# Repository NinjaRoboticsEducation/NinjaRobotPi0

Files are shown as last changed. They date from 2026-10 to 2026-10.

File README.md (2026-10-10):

# NinjaRobotPi0

<div align="center">

**An Educational Raspberry Pi Zero 2 W Robot — Build It, Program It, Bring It to Life**






</div>

---

**🌐 Language / 言語 / 語言 / 语言:**
[English](#english) ・ [日本語](#日本語) ・ [繁體中文](#繁體中文) ・ [简体中文](#简体中文)

---

<!-- ENGLISH -->

# English

## 1. What Is NinjaRobotPi0?

**NinjaRobotPi0** is an open-source, modular educational robot built on the **Raspberry Pi Zero 2 W** (a tiny, affordable computer about the size of a stick of gum). It brings together servo motors (for movement), an LCD display (the robot's face), a buzzer (for sounds and melodies), a distance sensor, cloud AI chat (Google, OpenAI, Anthropic or Ollama Cloud), Bluetooth Low Energy (BLE), and a browser-based control interface — all in one compact package.

Whether you want to build a tire-type car, a humanoid, or a spider robot, NinjaRobotPi0 gives you the foundation to learn how software, AI, and physical components work together.

### What can it do?

- **Move and express itself** — Use the built-in movement library to make your robot walk, wave, or dance. The LCD face shows animated expressions, and the buzzer plays emotion sounds.
- **Sense distance** — A VL53L0X laser sensor measures distances in millimetres, so your robot can detect obstacles.
- **Chat with AI** — Choose a cloud provider and connect its API key to chat with the AI. The AI can even trigger robot actions like movements and expressions.
- **Control from your phone** — Open a web browser on any device and you get a control panel with Home, Agent (AI chat), and Help pages — in English, Japanese, Traditional Chinese, and Simplified Chinese.
- **Learn step by step** — Calibrate each component with guided tools, then explore the Python packages and web interface at your own pace.

### Who is this for?

Anyone who wants to build their own AI robot! Whether you are a student learning about robotics, a maker exploring hardware, or a developer who wants to extend the platform — NinjaRobotPi0 provides a starting point; each assembled robot still needs installation, wiring and calibration checks on the real device.

---

## 2. Quick Start Guide

Follow these steps to build and run your own NinjaRobotPi0 from scratch.

### 2.1 Recommended Hardware

| Component | Specification | Notes |
|---|---|---|
| **Computer** | Raspberry Pi Zero 2 W (with GPIO header) | The brain of the robot |
| **Operating System** | Raspberry Pi OS 64-bit (Bookworm or Trixie) | Debian-based, no desktop needed |
| **Storage** | microSD card, 16 GB or larger | Leave space for dependencies and frontend build |
| **Pi Power** | Regulated 5 V supply via micro-USB | Powers the Pi only |
| **Servos** | Up to 8× SG90 / MG90S micro servos | Choose servo types suitable for your mechanism; positional SG90/MG90S servos do not provide continuous wheel rotation |
| **Servo Power** | Separate 5 V 3 A+ supply for servos | Size for the servos’ combined stall current; **must not** go through the Pi’s power pins |
| **Display** | ST7789V SPI LCD, 240 × 320 pixels | The robot's face screen |
| **Distance Sensor** | VL53L0X Time-of-Flight (I2C) | Measures distance using a laser |
| **Buzzer** | Passive buzzer (3–5 V) | For sounds and melodies |
| **Setup Access** | Terminal or SSH, internet, normal user with sudo | For installation and configuration |

> **📎 Full hardware details:** See the [Installation Guide](ninjarobot_pi0_Wiki/raw/articles/ninjarobotpi0/2026-10-10-model-adapter/InstallationGuide.md)

### 2.2 Hardware Wiring

Power off the Pi before connecting any wires. Keep servo power **disconnected** while installing software. The servo supply must **not** pass through the Pi's power pins — connect the servo power supply's ground and the Pi's ground together (common ground).

#### Pin Connections

| Component | Connection Type | Pin / Address |
|---|---|---|
| Servo signal wires (up to 8) | GPIO PWM | GPIO 20–27 (use the pins for your build) |
| ST7789V display — data | SPI0 | MOSI → GPIO 10 (Pin 19), SCLK → GPIO 11 (Pin 23), CE0 → GPIO 8 (Pin 24) |
| ST7789V display — control | GPIO (configurable) | DC → GPIO 14 (Pin 8), RST → GPIO 15 (Pin 10), Backlight → GPIO 16 (Pin 36) |
| VL53L0X distance sensor | I2C bus 1 | SDA → GPIO 2 (Pin 3), SCL → GPIO 3 (Pin 5) |
| Passive buzzer | GPIO | Signal → GPIO 17 (Pin 11), Ground → GND |

```
┌─────────────────────────────────────────┐
│         Raspberry Pi Zero 2 W           │
│                                         │
│  GPIO 20–27 ─────── Servo signals (×8)  │
│  GPIO 10,11,8 ────── ST7789V SPI data   │
│  GPIO 14,15,16 ───── ST7789V control    │
│  GPIO 2,3 ─────────── VL53L0X I2C      │
│  GPIO 17 ──────────── Buzzer signal     │
│  GND ──────────────── Common ground     │
└─────────────────────────────────────────┘
            │                    │
     Pi 5V micro-USB     Separate 5V supply
     (Pi power only)     (servo power only)
                    ↕ shared GND ↕
```

> ⚠️ **Safety:** Never change wiring while the Pi is powered on. Do not use the same GPIO pin for two components. GPIO numbers here are **BCM numbers**, not physical header positions. Pi GPIO uses **3.3 V logic**; never apply 5 V to a GPIO. Verify the module’s power/driver requirements. Display control pins are configurable — register your actual assignments during setup.

### 2.3 Raspberry Pi OS Installation

1. **Download Raspberry Pi Imager** from [raspberrypi.com/software](https://www.raspberrypi.com/software/) on your computer.
2. Insert your microSD card and open the Imager.
3. Choose **Raspberry Pi OS (64-bit)** — Bookworm or Trixie. The Lite (no desktop) edition works fine.
4. Open the Imager's **OS customisation** screen to configure:
   - Set your hostname (e.g., `ninjarobotpi0`)
   - Enable SSH (using an SSH key or password authentication)
   - Set your Wi-Fi network name and password
   - Set your username and password
5. Write the image to your microSD card and insert it into the Pi.
6. Power on the Pi and wait a few minutes for first-boot setup.
7. From your computer, connect via SSH:

   ```bash
   ssh YOUR_USERNAME@ninjarobotpi0.local
   ```

   Replace `YOUR_USERNAME` with the username you set in the Imager. If `.local` does not resolve, use the Pi's IP address instead.

8. Enable the hardware interfaces your components need:

   ```bash
   sudo raspi-config
   ```

   - Enable **I2C** (for the distance sensor)
   - Enable **SPI** (for the display)
   - If using GPIO 14/15 for the display, **disable the serial login console and the serial-port hardware assigned to those pins** so UART does not conflict with the display

   Reboot when prompted:

   ```bash
   sudo reboot
   ```

9. After reboot, verify your setup:

   ```bash
   uname -m                         # Should show: aarch64
   cat /etc/os-release              # Inspect OS identity; Bookworm/Trixie are reference releases
   ```

### 2.4 Project Installation

#### Default installation (recommended)

Run this single command in your Pi's terminal. It clones the project into `~/NinjaRobotPi0`, installs system prerequisites and prepares the project environment:

```bash
curl -fsSL https://raw.githubusercontent.com/NinjaRoboticsEducation/NinjaRobotPi0/HEAD/install.sh | bash
```

When prompted, read the installation plan and type `INSTALL` to confirm. The installer will:

- Create the `$HOME/NinjaRobotPi0` directory
- Install system packages, locked Python dependencies and the web frontend; reuse compatible Node/uv or download verified fallback tools
- Set up the locked Python environment in `.venv`

> **Note:** `HEAD` follows the repository's default branch. Do **not** prefix the command with `sudo`. The installer will ask for your sudo password only when it needs to install system packages.

#### Custom folder installation (alternative)

If you want to install into a different location (e.g., `~/Projects/NinjaRobotPi0`):

```bash
mkdir -p "$HOME/Projects"
curl -fsSL https://raw.githubusercontent.com/NinjaRoboticsEducation/NinjaRobotPi0/HEAD/install.sh | bash -s -- --install-dir "$HOME/Projects/NinjaRobotPi0"
```

The `--install-dir` path must be absolute (starting with `/`), must not already exist, and its parent folder must already exist.

#### After installation

Once the installer prints **Software installed**, verify the installation and start the pigpio daemon (a background service that controls GPIO pins):

```bash
cd "$HOME/NinjaRobotPi0" &&
./install.sh --check &&

# Start pigpio now:
sudo systemctl start pigpiod

# Optional: make pigpio start automatically on future boots:
sudo systemctl enable pigpiod
```

> **Important:** The installer leaves `pigpiod` inactive and does not enable autostart. Use your chosen installation path if it differs from the default. `pigpiod` is required for servo, buzzer, and other GPIO hardware to work. If you skip this step, hardware tools will fail to connect.

### 2.5 Onboarding — Set Up Your Robot

The onboarding wizard guides you through calibrating each hardware component and setting up your accounts. Before starting, make sure:

- All wiring is complete
- Servos are supported (wheels raised, limbs held) so they can move safely
- You are ready to remove servo power if anything goes wrong

Start the wizard:

```bash
./onboard.sh
```

The wizard walks you through these steps in order:

| Step | What you do | How you know it worked |
|---|---|---|
| **1. Display** | Enter your display's actual GPIO pins, set orientation and brightness | You see a test image on the LCD screen |
| **2. Buzzer** | Confirm the buzzer pin and play a test tone | You hear a short beep, then silence |
| **3. Servo** | Type `READY` only after supporting the robot; calibrate each servo's range and neutral point | Each servo moves to its expected position |
| **4. Distance** | Read sensor values, then calibrate at a known distance | Readings match the real distance |
| **5. Import** | Import display, buzzer, and servo settings into the main `config.json` | All settings pass validation |
| **6. Identity** | Set a BLE name and choose your robot type: `tire`, `humanoid`, or `spider` | Name and type match your build |
| **7. Select model provider** | Choose Google, OpenAI, Anthropic or Ollama Cloud; enter a hidden API key and select a live model | Model validates successfully (internet required; small provider charge possible) |
| **8. ngrok** | Optionally enter your ngrok authtoken for remote access | Token is saved (no tunnel opens yet) |

> ⚠️ **Servo warning:** The servo tool can **immediately move** previously calibrated servos when it opens — even before its menu appears. Always support the robot before opening the servo tool.

**When valid settings already exist**, choose **2) Apply existing settings for all modules** to reuse them and only configure remaining modules.

**Useful onboarding commands:**

```bash
./onboard.sh --dry-run         # Preview without changing anything
./onboard.sh --status          # Check current progress and file validity
./onboard.sh --resume          # Resume from where you left off
./onboard.sh --step servo      # Jump to a specific step
./onboard.sh --step gemini     # Change your API key or model
./onboard.sh --step ngrok      # Configure remote access token
```

Press **Q** or **Ctrl+C** to save progress and exit. The wizard does not start the server on exit.

### Choose or change the agent model

Run `uv run ninja_core config select-model` (also available in `ninja_core init-tool`, option 1, or `./onboard.sh --step ai_model`). Choose **Google, OpenAI, Anthropic, or Ollama Cloud**, enter your API key privately, then select and validate an available model. Restart the running agent/server deliberately to apply a CLI change. Account login is a later feature; use provider API credentials rather than a ChatGPT/Claude subscription password.

`./install.sh` installs the Ollama CLI automatically; Pi0 uses Ollama Cloud, with no local models or daemon. The official ARM64 archive needs 2 GB free temporary disk space. New keys are stored under `~/.config/ninjarobot_pi0/credentials/` (or `$XDG_CONFIG_HOME`); protect that directory and `config.pre-provider.json`. Web microphone input uses browser speech recognition and works with every model provider; uploaded audio files require a supported Gemini model. Cloud calls may incur charges. Detailed behavior and manual validation are in the [model adapter wiki source](ninjarobot_pi0_Wiki/raw/notes/ninjarobotpi0/2026-10-10-model-adapter/ModelAdapterImplementation.md).

### 2.6 Create Robot Movements

Use the `movement-tool` to create custom movement sequences (walking patterns, dance moves, gestures):

```bash
.venv/bin/ninja_core movement-tool
```

The movement tool lets you:

- **Move individual servos** to specific angles with speed control
- **Record multi-servo poses** as steps in a sequence
- **Play back sequences** with smooth, position-aware easing (acceleration at the start, constant speed in the middle, deceleration at the end)

**Movement command format:**

```
[SPEED_]PIN:ANGLE[SPEED][/PIN:ANGLE[SPEED]...]
```

| Example | What it does |
|---|---|
| `20:45` | Move GPIO 20 to 45° at medium speed |
| `20:C` | Move GPIO 20 to centre (0°) |
| `S_20:45/21:-30` | Move two servos at slow speed |
| `M_20:C/21:45F` | Global medium speed, but GPIO 21 targets 45° at fast speed |

**Speed letters:** `F` = Fast, `M` = Medium (default), `S` = Slow
**Angle keywords:** `C` = Centre (0°), `M` = Min (−90°), `X` = Max (90°)

### 2.7 Start the Server and Use the Web Interface

Keep the robot supported for the first start. From the project root:

```bash
.venv/bin/ninja_core server
```

The server initialises hardware and may centre servos. At the ngrok prompt, press Enter to retain the token saved during onboarding; enter or change tokens through onboarding’s hidden input. The current server attempts ngrok connections even if you skipped that step, so skipping it is **not a local-only mode**. A working token can expose the control interface publicly.

#### Open the web interface

Open the **Local Access** URL printed by the server (usually `http://<pi-address>:8000`) from any device on the same network.

The web interface has three pages:

| Page | What it does |
|---|---|
| **Home** | Robot entry page with a power-off slider control |
| **Agent** | AI chat with your selected provider, expressions, sounds, movements, and distance readings |
| **Help** | Usage guidance; the menu also lets you switch the interface language |

> **Note:** The BLE badge on screen means the robot is **advertising** (broadcasting its Bluetooth signal), not that a controller is connected. Browser speech input depends on browser support and permissions.

---

### 2.8. Automatic Startup (Optional)

If you want the robot to start automatically when you turn on the power, follow these steps.

> [!IMPORTANT]
> **Prerequisites:** Ensure you have completed all previous steps, including hardware calibration and API key setup. The robot must be fully functional before enabling autostart.
>
> **Ngrok requirement:** Autostart checks that a saved token exists and aborts if none is found. Token presence does not prove validity; verify manual server startup first.

#### Step1: Install the Startup Service

From the project root, as your normal user, select a compatible uv using the installer’s checker, then run the service helper:

```bash
NINJAROBOT_UV="$(python3 -B scripts/install_check.py --find-tool uv)" &&
PATH="$(dirname -- "$NINJAROBOT_UV"):$PATH" .venv/bin/ninja_utils install-startup
```

This will:

1. Check if your system is ready (config exists, pigpiod running, etc.)
2. Create a systemd service file
3. Enable the service for future boots; it does **not** start the robot immediately. The existing service runs `uv run ninja_core server --autostart`, which may sync Python dependencies at startup.

#### Step2: Verify

You can check the status of the service; enabled but inactive is expected until it is started or the Pi reboots:

```bash
.venv/bin/ninja_utils status-startup
```

#### Step3: Reboot

Reboot your Raspberry Pi:

```bash
sudo reboot
```

After reboot, check the service again. Use your actual hostname or Pi IP address (for example, `http://ninjarobotpi0.local:8000`). A QR code is shown only if the display and public tunnel succeed; startup time varies.

> [!TIP]
> **Shutdown:** The Home page’s power slider and confirmation request shutdown. The robot attempts a face/sound animation and the configured `Poweroff` movement, so keep it supported. OS shutdown requires permission to run `sudo shutdown`; if it fails, use `sudo shutdown -h now` from SSH. Confirm the OS has halted before removing power; an idle LED alone is not proof.

#### Removing Autostart

If you want to stop the robot from starting automatically:

```bash
.venv/bin/ninja_utils remove-startup
```

---

## 3. NinjaRobotPi0 File Structure

```
NinjaRobotPi0/
├── ninja_core/               # Central server: HAL, motion, AI agent, web server
├── ninja_ble/                # Bluetooth Low Energy GATT service
├── ninja_utils/              # Shared interfaces, logging, and system utilities
├── ninja_webapp/             # React + Vite frontend (browser control interface)
├── pi0servo/                 # Servo motor driver (velocity-based, up to 8 servos)
├── pi0disp/                  # ST7789V LCD display driver (face expressions)
├── pi0buzzer/                # Passive buzzer driver (sounds and melodies)
├── pi0vl53l0x/               # VL53L0X distance sensor driver
├── ninjarobot_pi0_Wiki/      # Built-in project knowledge base
├── scripts/                  # Installation and maintenance scripts
├── tests/                    # Automated test suite
├── docs/                     # Validation reports and documentation
├── 3Dmodels/                 # 3D-printable robot chassis models
├── assets/                   # Static resources (images, etc.)
├── config.json               # Robot configuration (identity, hardware, Gemini key)
├── servo.json                # Servo calibration data
├── install.sh                # One-command installer
├── onboard.sh                # Guided setup wizard entry point
├── pyproject.toml            # Python project metadata and dependencies
└── README.md                 # This file
```

---

### Built-in movements by robot type

After calibrating the servos for your build, select the robot type and import the module settings. These commands only update configuration data:

```bash
.venv/bin/ninja_core config set-type spider  # Or wheel / humanoid; wheel is saved as tire
.venv/bin/ninja_core config import
```

Spider receives 19 `spider_*` movements and the exact `Poweroff` pose from the Spider proposal when GPIO20–27 are configured. Wheel and Humanoid currently receive only `home`, which commands every configured servo to 0° at Slow speed. Their other default movements will be added later. No movements run during import. Restart an already running server/tool deliberately to load the updated configuration.

Once the robot is supported and ready to move, use movement-tool option 4, the web Agent page's movement dropdown, or ask Ninja agent for an available movement. Opening movement-tool or starting the server can initialize hardware; server shutdown can run `Poweroff`. Spider's sampled waypoints preserve targets, not OTTO's exact timing or physical walking distance. Validate direction, clearance, power and calibration before grouped motion, especially the ±90° shutdown pose.

Reimport preserves custom sequences and edited built-ins. Type changes remove only unchanged imported built-ins; edited movements retain their type scope and are hidden/rejected on incompatible profiles. Native playback validates the entire sequence before its first servo command. Invalid or incompatible web requests return an error and are recorded in the page's log. Missing active channels also block playback. Built-ins can be restored by removing an unwanted edited entry and importing again; back up your configuration first. Existing custom `home`/`Poweroff` name collisions are preserved rather than overwritten.

日本語: 校正後にロボット種類を設定し、`config import` を実行すると対応する動作が追加されます。Wheel と Humanoid は現在、全設定サーボを中心に戻す `home` のみです。インポートではサーボは動きません。実行前に機体を支え、配線・方向・可動範囲・電源を確認してください。Spider の `Poweroff` は終了処理でも動く場合があります。

繁體中文：完成校正後設定機器人類型，再執行 `config import`，即可加入適用動作。Wheel 與 Humanoid 目前只有將所有已設定伺服機回中的 `home`。匯入不會驅動硬體。執行前請支撐機體並確認接線、方向、活動範圍與電源；Spider 的 `Poweroff` 也可能在結束伺服器時執行。

The [implementation plan](docs/BuiltinMovementsImplementationPlan.md) and [validation report](docs/validation/BuiltinMovements-2026-10-09.md) record the built-in movement implementation and its original validation status.

### Exit, reconnect and environment prompt

Movement-tool **6. Exit** executes configured `Poweroff` before HAL shutdown, without a following center command. Wheel/Humanoid without `Poweroff` use their configured `home`. Invalid/incompatible poses are refused; shutdown and configuration save still run. Opening the tool centers servos, and exiting can move them; check clearance and support the robot first. Shutdown releases PWM, so the final pose is not held electrically afterward.

One browser identity controls the web interface at a time; tabs sharing its session cookie count as one controller. Home/Agent/Help navigation retains the connection. Closing its last tab restores the saved ngrok QR (or LAN QR if tunneling failed), stops active browser-owned work and permits another browser to connect. A lost network is released after 35 seconds without a heartbeat; browsers retry every 3 seconds. Missing/failing displays do not prevent reconnection. This ownership guard is not login authentication, and BLE remains a separate existing protocol. REST `/api/` calls and distance/events sockets require the active browser session; inactive API requests return 423.

The installer retains the `.venv` directory and now sets its prompt to `(ninjarobotpi0)` with `uv venv --allow-existing --prompt ninjarobotpi0`, then performs locked synchronization. It does not clear the environment. Re-activate your current shell after upgrading: `deactivate` (if active), then `source .venv/bin/activate`. The local environment's activation scripts have also been updated without reinstalling packages.

日本語：移動ツールの「6. Exit」は `Poweroff`（未設定の Wheel/Humanoid は `home`）を実行してから終了し、再センタリングしません。最後のタブを閉じると再接続 QR を表示します。同時操作は一つのブラウザー識別情報に限定され、通信断はハートビート未受信から 35 秒で解放します。`.venv` の表示名は `ninjarobotpi0` です。終了時にも動くため、機体を支えて可動範囲を確認してください。

繁體中文：移動工具選擇「6. Exit」會先執行 `Poweroff`（未設定 Poweroff 的 Wheel/Humanoid 使用 `home`），之後不再回中。關閉最後一個分頁後重新顯示連線 QR；同時僅允許一個瀏覽器身分控制，35 秒未收到心跳即釋放連線。`.venv` 顯示名稱改為 `ninjarobotpi0`。結束時仍可能移動，請先支撐機體並確認活動範圍。

简体中文：移动工具选择「6. Exit」会先执行 `Poweroff`（未配置 Poweroff 的 Wheel/Humanoid 使用 `home`），之后不再回中。关闭最后一个标签页后重新显示连接 QR；同时仅允许一个浏览器身份控制，35 秒未收到心跳即释放连接。`.venv` 显示名称改为 `ninjarobotpi0`。退出时仍可能移动，请先支撑机体并确认活动范围。

See the [lifecycle plan](docs/LifecycleRefinementsImplementationPlan.md) and [validation report](docs/validation/LifecycleRefinements-2026-10-10.md). New lifecycle raw manual versions await the owner's ingestion/review; existing wiki pointers remain unchanged.

## 4. Troubleshooting

### `uv run` cannot spawn `ninja_core` after upgrading

`Failed to spawn: ninja_core` / `No such file or directory` means the CLI launcher is missing, not that the server rejected your configuration. The former root project duplicated five package-owned console scripts; an upgrade could remove those shared files even though provider packages stayed installed. The root now delegates commands to their packages, and the installer reinstalls/checks all five providers. A normal sync can leave already-missing launchers untouched.

From your existing checkout containing this fix, stop any running robot in a controlled maintenance session first (shutdown may execute Poweroff), then repair Python as your normal user:

```bash
cd /home/rogerchang/NinjaRobotPi0  # Use your actual checkout path
env -u UV_PROJECT_ENVIRONMENT -u UV_PROJECT uv sync --locked --inexact --no-dev \
  --reinstall-package ninja-core --reinstall-package pi0servo \
  --reinstall-package pi0disp --reinstall-package pi0buzzer \
  --reinstall-package pi0vl53l0x
uv run --no-sync ninja_core --help
./install.sh --check
```

`--inexact` preserves unrelated/dev packages; configuration/calibration is retained. This does not perform apt installation or start hardware/services. If dependencies/interpreter are absent, use the full installer after `./install.sh --dry-run`. For another checkout, first publish this fix, check `git status`, then `git pull --ff-only` on the intended tracking branch; stop on Git errors and preserve local changes. Do not delete `.venv` or your configuration as a first recovery step.

Only after CLI help succeeds **and physical readiness is confirmed**, run `uv run --no-sync ninja_core server` (or `.venv/bin/ninja_core server`). Startup can energize/center servos, initialize display/buzzer and open ngrok; it is not a non-moving smoke test. See [repair plan](docs/CLIEntryPointRepairPlan.md) and [validation](docs/validation/CLIEntryPoints-2026-10-10.md).

### Installation stopped before Python setup

`Stop pigpiod ... first` or `Stop ninjarobot ... first` means installation stopped **before** dependencies were installed. `PASS: software prerequisites` at this stage is only platform/path preflight; success is **Software installed**. Missing `.venv/bin/ninja_core` or package metadata is an incomplete installation, not a version mismatch.

Support the robot and disconnect actuator power before stopping the foreground robot application. Stop any active robot service **before** pigpiod; then retry from the existing folder:

```bash
sudo systemctl stop ninjarobot   # Only if this service is installed/running
sudo systemctl stop pigpiod
cd "$HOME/NinjaRobotPi0" && ./install.sh && ./install.sh --check
```

Keep configuration/calibration files. If installation fails again, retain the **first error**; `--check` only inspects and does not repair. After successful installation, start pigpiod again before hardware use. To update an existing checkout first, use `git fetch origin HEAD && git merge --ff-only FETCH_HEAD`; stop if Git reports an error. The installer itself does not update existing Git files.

### Installation Issues

| Problem | Solution |
|---|---|
| `curl` returns 404 | The installer must be published to the official repository first. For pre-publication testing, use the local checkout: `cd /path/to/NinjaRobotPi0 && ./install.sh` |
| `Unsupported platform` error | Verify: Raspberry Pi Zero 2 W, `uname -m` shows `aarch64`, Debian-based Raspberry Pi OS 64-bit, Python 3.10+, and you are logged in as a normal user (not root). |
| `Destination already exists` | The installer will not overwrite an existing folder. Enter that folder and run: `cd "$HOME/NinjaRobotPi0" && ./install.sh` |
| Installation stops at OS packages | Check the error message — it is usually an `apt`, network, or `sudo` issue. Fix the underlying problem and re-run `./install.sh`. |
| `uv is not found` after install | Use `.venv/bin/ninja_core` for runtime commands. Compatible existing tools are reused; fallback tools are private. See the autostart section if that helper needs uv on PATH. |

### Hardware Issues

| Problem | Solution |
|---|---|
| Display stays blank | Check that SPI is enabled: `sudo raspi-config` → Interface Options → SPI → Enable. Verify wiring matches your configured pins. |
| Buzzer makes no sound | Make sure it is a **passive** buzzer (not active). Confirm it is connected to GPIO 17. |
| Servos do not move | Raise wheels/limbs first. Check `sudo systemctl status pigpiod` — it must be running. Verify wiring and re-run calibration. |
| Distance sensor not detected | Check that I2C is enabled. With robot/sensor tools stopped, use `i2cdetect -y 1` (from the optional `i2c-tools` package); the usual sensor address is `29` (0x29). |
| Hardware tool will not open | Stop the server first (`Ctrl+C`). Then check: is `pigpiod` running? Are I2C/SPI enabled? Are pin assignments correct? |
| Import blocked in onboarding | Complete valid display, buzzer, and servo calibration first. Factory-default files are not accepted. |
| Port 8000 is busy | Identify the listener first. Stop a foreground robot with `Ctrl+C`, or its managed service with `sudo systemctl stop ninjarobot`; stopping can execute the configured shutdown movement. |

### Server / AI Issues

| Problem | Solution |
|---|---|
| Model setup fails | Check your internet connection and API key. Retry with: `./onboard.sh --step gemini` |
| ngrok setup fails | Check your internet connection and authtoken. Retry with: `./onboard.sh --step ngrok` |
| Server starts but web page is unreachable | Make sure your phone/computer is on the same Wi-Fi network as the Pi. Try using the Pi's IP address directly. |

---

## 5. Appendix

### Appendix A: Google Gemini API Key

To use the AI chat feature, you need a Google Gemini API key. Free-tier availability and quotas depend on the model, project and region. Here is how to get one:

#### Step 1 — Open Google AI Studio

1. Go to [Google AI Studio](https://aistudio.google.com/) in your browser.
2. Sign in with your Google account.

#### Step 2 — Create an API key

1. Click **Get API key** in the left sidebar (or top navigation).
2. Click **Create API key**.
3. Choose an existing Google Cloud project or create one, then check its quota and billing settings.
4. Copy the generated API key privately; do not include it in screenshots, logs or Git commits.

#### Step 3 — Save the key on your Pi

Choose Google in onboarding step 7, **Select model provider**, to enter your Gemini API key. Paste it in — the input is hidden for security. The wizard then lets you choose from the available AI models associated with your key.

If you already completed onboarding and want to change the key:

```bash
./onboard.sh --step gemini
```

> **Note:** The free tier of the Gemini API has usage limits. Check [Google AI pricing](https://ai.google.dev/gemini-api/docs/pricing) for current details.

### Appendix B: ngrok Account Setup

[ngrok](https://ngrok.com/) lets you access your robot from outside your home network (for example, from your office or while travelling). It creates a secure tunnel from the internet to your Pi.

#### Step 1 — Create an ngrok account

1. Go to [ngrok.com](https://ngrok.com/) and click **Sign up** for a free account.
2. After logging in, go to **Your Authtoken** in the left sidebar of the ngrok dashboard.
3. Copy your authtoken (a long string that identifies your account).

> **Note:** The ngrok free plan has connection limits. See [ngrok pricing](https://ngrok.com/docs/pricing-limits/free-plan-limits) for details.

#### Step 2 — Save the token on your Pi

During onboarding, the wizard asks for your ngrok authtoken at the **ngrok** step. Paste it in — the input is hidden for security.

If you already completed onboarding and want to add or change the token:

```bash
./onboard.sh --step ngrok
```

The token is saved privately. No tunnel opens during onboarding — the tunnel starts only when you launch the server.

> ⚠️ **Security:** Never share your ngrok public URL or screenshot it. Anyone with the URL can control your robot until you stop the tunnel.

---

### Appendix C: Compatibility and reference checks

Bookworm/Trixie 64-bit are reference releases, not an OS-codename allowlist. The installer requires Zero 2 W, Linux `aarch64`, Debian-family Raspberry Pi OS, a normal user and Python 3.10+. Node must satisfy the locked Vite build range (20.19+ in 20.x, or >=22.12.0); uv is checked for required commands, not an exact version. Passing software checks does not certify an assembled robot.

From the installation folder, `./onboard.sh --status` checks saved configuration; `./onboard.sh --resume` resumes setup. These do not certify physical operation. Only run one hardware tool/server at a time. The movement tool can centre servos when recording starts; use only configured pins and mechanically safe angles. Per-servo speed suffixes in the core movement tool require numeric angles (for example `21:45F`, not `21:XF`).

Protect `config.json` (which may contain your Gemini key), ngrok credentials and calibration files; do not publish them. Gemini pricing/quota and ngrok availability depend on your account. The Pi0 control interface has no user-login protection; an encrypted ngrok tunnel does not add application authentication. Use trusted networks and keep control URLs private.

Full references: [Installation Guide](ninjarobot_pi0_Wiki/raw/articles/ninjarobotpi0/2026-10-10-model-adapter/InstallationGuide.md), [Development Guide](ninjarobot_pi0_Wiki/raw/articles/ninjarobotpi0/2026-10-11-shutdown-voice-fixes/DevelopmentGuide.md), [Development Log](ninjarobot_pi0_Wiki/raw/notes/ninjarobotpi0/2026-10-11-shutdown-voice-fixes/DevelopmentLog.md).

## License

NinjaRobotPi0 source code is licensed under the [MIT License](LICENSE).

<div align="center">

Made with ❤️ for AI Robotics Education

</div>

---
---

<!-- 日本語 -->

# 日本語

モデルの変更: `uv run ninja_core config select-model` または `./onboard.sh --step ai_model` で Google、OpenAI、Anthropic、Ollama Cloud を選び、API キーを非公開で入力してモデルを検証します。変更後はエージェントを手動で再起動してください。Pi0 はクラウド推論のみを使用します。インストーラーは Ollama CLI を導入します（ローカルモデルやデーモンなし、展開用の空き容量 2 GB が必要）。Web のマイク入力はブラウザーの音声認識を使い、すべてのモデルプロバイダーで利用できます。音声ファイルの送信には対応する Gemini モデルが必要です。クラウド利用は課金される場合があります。

## 1. NinjaRobotPi0 とは？

**NinjaRobotPi0** は、**Raspberry Pi Zero 2 W**（ガム一個分ほどの小さくて手頃なコンピュータ）で動くオープンソースの教育用ロボットです。サーボモーター（動き）、LCD ディスプレイ（ロボットの顔）、ブザー（音やメロディ）、距離センサー、Google Gemini AI チャット、Bluetooth Low Energy（BLE）、ブラウザ操作をひとつにまとめたコンパクトなパッケージです。

タイヤ型の車、ヒューマノイド、クモ型ロボットなど、好きな形で組み立てられます。ソフトウェア・AI・ハードウェアがどう連携するかを楽しく学べます。

### 何ができる？

- **動いて表情を見せる** — 内蔵の動作ライブラリで歩行・ウェーブ・ダンスが可能。LCD にアニメ表情、ブザーで感情サウンドを再生。
- **距離を測る** — VL53L0X レーザーセンサーがミリメートル単位で障害物を検知。
- **AI とチャット** — Google Gemini API キーを接続すれば AI と会話でき、動作やアクションも起動可能。
- **スマホから操作** — ブラウザで Home・Agent（AI チャット）・Help の 3 ページを操作。英語・日本語・繁體中文・简体中文に対応。
- **段階的に学べる** — ガイド付きツールで各部品を校正し、Python パッケージや Web インターフェースを自分のペースで探索。

---

## 2. クイックスタートガイド

### 2.1 推奨ハードウェア

| 部品 | 仕様 | 備考 |
|---|---|---|
| **コンピュータ** | Raspberry Pi Zero 2 W（GPIO ヘッダー付き） | ロボットの頭脳 |
| **OS** | Raspberry Pi OS 64-bit（Bookworm / Trixie） | Debian 系、デスクトップ不要 |
| **ストレージ** | microSD カード 16 GB 以上 | 依存関係とフロントエンドのビルド用 |
| **Pi 電源** | 5 V micro-USB 電源 | Pi 用のみ |
| **サーボ** | 最大 8 個の SG90 / MG90S マイクロサーボ | 車輪・腕・脚など用途に合わせて |
| **サーボ電源** | 別系統の 5 V 3 A+ 電源 | Pi の電源ピンを通さないこと |
| **ディスプレイ** | ST7789V SPI LCD 240×320 | ロボットの顔 |
| **距離センサー** | VL53L0X（I2C） | レーザー測距 |
| **ブザー** | パッシブブザー（3–5 V） | 音やメロディ用 |

### 2.2 配線

電源を切ってから配線してください。サーボ電源は別系統で、Pi の電源ピンを通さないでください。サーボ電源と Pi の GND は共有してください。

| 部品 | 接続先 |
|---|---|
| サーボ信号線（最大 8 本） | GPIO 20–27 |
| ST7789V SPI データ | MOSI → GPIO 10、SCLK → GPIO 11、CE0 → GPIO 8 |
| ST7789V 制御 | DC → GPIO 14、RST → GPIO 15、バックライト → GPIO 16 |
| VL53L0X | SDA → GPIO 2、SCL → GPIO 3 |
| ブザー | 信号 → GPIO 17 |

> ⚠️ **安全:** 通電中に配線を変更しないでください。

GPIO 番号は **BCM 番号**です（物理ピン番号ではありません）。GPIO は **3.3 V ロジック**で、5 V を入力してはいけません。モジュールの電源・駆動回路を確認し、サーボ電源は合計ストール電流に合わせて選んでください。SG90/MG90S の位置制御サーボは車輪を連続回転させるものではありません。

### 2.3 OS インストール

1. [raspberrypi.com/software](https://www.raspberrypi.com/software/) から **Raspberry Pi Imager** をダウンロード。
2. **Raspberry Pi OS 64-bit** を microSD に書き込み。ホスト名・SSH・Wi-Fi・ユーザー名を設定。
3. Pi に挿して起動、SSH で接続：
   ```bash
   ssh YOUR_USERNAME@ninjarobotpi0.local
   ```
4. `sudo raspi-config` で **I2C** と **SPI** を有効化。GPIO 14/15 をディスプレイに使う場合は、そのピンのシリアルコンソールと UART を無効化し、必要に応じて再起動。

### 2.4 プロジェクトのインストール

```bash
curl -fsSL https://raw.githubusercontent.com/NinjaRoboticsEducation/NinjaRobotPi0/HEAD/install.sh | bash
```

通常ユーザーで実行し、`INSTALL` と入力して確認。**Software installed** が表示された後に確認し、pigpiod を起動します（インストーラーは起動・自動起動設定を行いません）：

```bash
cd "$HOME/NinjaRobotPi0" &&
./install.sh --check &&

# pigpio を起動（GPIO ハードウェア制御に必要）：
sudo systemctl start pigpiod

# 任意：今後の起動時に自動で開始：
sudo systemctl enable pigpiod
```

**別フォルダにインストール** したい場合：

```bash
mkdir -p "$HOME/Projects"
curl -fsSL https://raw.githubusercontent.com/NinjaRoboticsEducation/NinjaRobotPi0/HEAD/install.sh | bash -s -- --install-dir "$HOME/Projects/NinjaRobotPi0"
```

> **重要:** 別フォルダを選んだ場合は、以降の `cd` をそのパスに置き換えてください。`pigpiod` はサーボ・ブザーなどの GPIO ハードウェア制御に必須です。

### 2.5 初期設定ウィザード

サーボの支えを確認してから実行：

```bash
./onboard.sh
```

| ステップ | 内容 |
|---|---|
| 1. ディスプレイ | GPIO ピン設定、向き・明るさテスト |
| 2. ブザー | ピン設定、テスト音再生 |
| 3. サーボ | `READY` 入力後、各サーボの範囲と中立点を校正 |
| 4. 距離 | センサー読み取り値を確認・校正 |
| 5. 取り込み | 設定を `config.json` にインポート |
| 6. 名前/型 | BLE 名とロボットタイプ（`tire`/`humanoid`/`spider`）を設定 |
| 7. モデルプロバイダー選択 | Google / OpenAI / Anthropic / Ollama Cloud の API キーとモデルを設定 |
| 8. ngrok | リモートアクセス用トークン設定（任意） |

> ⚠️ **注意:** サーボツールは開くと**即座に**校正済みサーボを動かす場合があります。必ずロボットを支えてから開いてください。

### 2.6 動作の作成

```bash
.venv/bin/ninja_core movement-tool
```

サーボを個別に動かし、ポーズを記録してシーケンスを作成できます。

**動作コマンドの形式：**

```
[スピード_]ピン:角度[スピード][/ピン:角度[スピード]...]
```

| 例 | 動作内容 |
|---|---|
| `20:45` | GPIO 20 を 45° に中速で移動 |
| `20:C` | GPIO 20 を中央（0°）に移動 |
| `S_20:45/21:-30` | 2 つのサーボを低速で同時移動 |

**スピード:** `F` = 高速、`M` = 中速（デフォルト）、`S` = 低速
**角度キーワード:** `C` = 中央（0°）、`M` = 最小（−90°）、`X` = 最大（90°）

### 2.7 サーバー起動と Web インターフェース

サーバーはハードウェアを初期化し、サーボを中央に動かす場合があります。ngrok の確認では Enter で保存済みトークンを保持します。トークンの入力・変更にはウィザードの非表示入力を使ってください。ngrok の設定を省略しても接続は試行されるため、ローカル専用モードにはなりません。

```bash
.venv/bin/ninja_core server
```

表示された **ローカル URL**（通常 `http://<Pi のアドレス>:8000`）をスマホで開いてください。

| ページ | 機能 |
|---|---|
| **Home** | ロボットのホーム画面、電源オフ制御 |
| **Agent** | AI チャット、表情・サウンド・動作 |
| **Help** | 使い方ガイド、言語切替 |

---

### 2.8 自動起動（オプション）

電源を入れたときにロボットを自動的に起動させたい場合は、次の手順に従ってください。

> [!IMPORTANT]
> **前提条件:** ハードウェアの校正やAPIキーの設定など、前のすべての手順を完了していることを確認してください。自動起動を有効にする前に、ロボットが完全に機能している必要があります。
>
> **ngrok の要件:** 自動起動は保存済みトークンの存在を確認し、なければ終了します。存在だけでは有効性を保証しないため、先に手動で起動を確認してください。

#### ステップ1: スタートアップサービスのインストール

プロジェクトのルートで通常ユーザーとして実行します。インストーラーの確認ツールで互換性のある uv を選び、サービス設定に使用します：

```bash
NINJAROBOT_UV="$(python3 -B scripts/install_check.py --find-tool uv)" &&
PATH="$(dirname -- "$NINJAROBOT_UV"):$PATH" .venv/bin/ninja_utils install-startup
```

これにより:

1. システムの準備ができているか確認します（configが存在するか、pigpiodが実行されているかなど）
2. systemdサービスファイルを作成します
3. 次回起動時に有効化します。この操作だけではロボットは起動しません。既存サービスは `uv run ninja_core server --autostart` を使うため、起動時に Python 依存関係を同期する場合があります。

#### ステップ2: 確認

サービスの状態を確認できます。手動起動または再起動までは、有効でも inactive（停止中）と表示されるのが通常です：

```bash
.venv/bin/ninja_utils status-startup
```

#### ステップ3: 再起動

Raspberry Piを再起動します:

```bash
sudo reboot
```

再起動後にサービスの状態を確認し、実際のホスト名または IP アドレス（例：`http://ninjarobotpi0.local:8000`）を使ってください。QR コードはディスプレイと公開トンネルが動作した場合だけ表示され、起動時間も環境に依存します。

> [!TIP]
> **シャットダウン:** Home の電源スライダーと確認操作で終了を要求します。表情・音・設定済みの `Poweroff` 動作を試みるため、ロボットを支えてください。OS 停止には `sudo shutdown` の権限が必要です。失敗時は SSH で `sudo shutdown -h now` を実行し、OS の停止を確認してから電源を抜いてください。LED の消灯だけでは停止を確認できません。

#### 自動起動の削除

ロボットの自動起動を停止したい場合:

```bash
.venv/bin/ninja_utils remove-startup
```

---

## 3. ファイル構成

```
NinjaRobotPi0/
├── ninja_core/               # サーバー本体: HAL・動作・AI・Web
├── ninja_ble/                # BLE GATT サービス
├── ninja_utils/              # 共有インターフェースとユーティリティ
├── ninja_webapp/             # React + Vite フロントエンド
├── pi0servo/                 # サーボドライバー
├── pi0disp/                  # LCD ディスプレイドライバー
├── pi0buzzer/                # ブザードライバー
├── pi0vl53l0x/               # 距離センサードライバー
├── ninjarobot_pi0_Wiki/      # プロジェクト Wiki
├── install.sh                # ワンコマンドインストーラー
├── onboard.sh                # 初期設定ウィザード
└── config.json               # ロボット設定ファイル
```

---

## 4. トラブルシューティング

### 更新後に `ninja_core` を起動できない場合

`Failed to spawn` / `No such file or directory` は CLI 起動ファイルがないことを示します。以前はルートと個別パッケージが同じ起動ファイルを所有していました。修正で重複を解消し、インストーラーが五つを再作成・確認します。稼働中のロボットを安全に停止してから（Poweroff が動く場合があります）、修正済みフォルダーで通常ユーザーとして実行してください：

```bash
env -u UV_PROJECT_ENVIRONMENT -u UV_PROJECT uv sync --locked --inexact --no-dev --reinstall-package ninja-core --reinstall-package pi0servo --reinstall-package pi0disp --reinstall-package pi0buzzer --reinstall-package pi0vl53l0x
uv run --no-sync ninja_core --help
./install.sh --check
```

校正・設定と既存の開発用パッケージは保持します。別のフォルダーでは修正の公開後に `git status`、`git pull --ff-only` の順に確認し、Git エラー時は停止してください。ヘルプ成功と実機準備の確認後のみ `uv run --no-sync ninja_core server` を実行します。起動はハードウェアを動かす場合があります。

### Python 導入前に停止する場合

`Stop pigpiod ... first` / `Stop ninjarobot ... first` は依存関係の導入**前**の停止です。この段階の `PASS: software prerequisites` は OS・パスの確認のみで、完了は **Software installed** です。`.venv/bin/ninja_core` やパッケージ情報がない場合は導入未完了です。

本体を支えてアクチュエータ電源を外してから、手動起動したロボットを停止します。ロボットサービスを先に停止し、既存フォルダで再実行してください：

```bash
sudo systemctl stop ninjarobot   # このサービスを導入・起動している場合のみ
sudo systemctl stop pigpiod
cd "$HOME/NinjaRobotPi0" && ./install.sh && ./install.sh --check
```

校正・設定を削除せず、再失敗時は最初のエラーを保存してください。`--check` は修復しません。完了後、ハードウェア使用前に pigpiod を再起動します。既存コードの更新は `git fetch origin HEAD && git merge --ff-only FETCH_HEAD` を使い、Git エラー時は停止してください。インストーラーは既存 Git ファイルを更新しません。

| 問題 | 解決方法 |
|---|---|
| `curl` が 404 を返す | リポジトリに公開後、再実行してください |
| 対応外プラットフォーム | Zero 2 W / aarch64 / Raspberry Pi OS 64-bit / Python 3.10+ / 通常ユーザーを確認 |
| ディスプレイが表示されない | SPI 有効化を確認：`sudo raspi-config` → SPI |
| サーボが動かない | `sudo systemctl status pigpiod` で起動確認。車輪を浮かせて再校正 |
| ポート 8000 が使用中 | 既存のサーバーインスタンスを停止してから再起動 |
| Gemini の設定失敗 | インターネット接続と API キーを確認。再試行: `./onboard.sh --step gemini` |

---

## 5. 付録

### 付録 A: Google Gemini API キー

1. [Google AI Studio](https://aistudio.google.com/) にアクセスしてログイン。
2. **Get API key** → **Create API key** をクリック。
3. プロジェクトを選択し、利用可能なモデル・割り当て・課金設定を確認。
4. 生成されたキーをコピーし、初期設定ウィザードの Gemini ステップで入力。

変更する場合：`./onboard.sh --step gemini`

> **注意:** 無料枠には使用制限があります。詳細は [Google AI の料金ページ](https://ai.google.dev/gemini-api/docs/pricing) をご確認ください。

### 付録 B: ngrok アカウント設定

1. [ngrok.com](https://ngrok.com/) で無料アカウントを作成。
2. ダッシュボードの **Your Authtoken** からトークンをコピー。
3. 初期設定ウィザードの ngrok ステップで入力。

変更する場合：`./onboard.sh --step ngrok`

> ⚠️ ngrok の公開 URL は他人に共有しないでください。URL を知っている人がロボットを操作できてしまいます。

---

### 付録 C: 互換性と確認用リファレンス

Bookworm/Trixie 64-bit は参照環境であり、OS コードネームの許可リストではありません。Zero 2 W、Linux `aarch64`、Debian 系 Raspberry Pi OS、通常ユーザー、Python 3.10+ が必要です。Node は 20.x の 20.19+ または 22.12.0 以降、uv は必要なコマンドに対応していれば完全一致の版は不要です。ソフトウェアの確認だけでは実機の動作を保証しません。

カスタムインストール先は未作成の絶対パスを指定し、親フォルダを先に作ってください。`sudo` を付けずにインストールします。`YOUR_USERNAME` とホスト名は Imager で設定した値に置き換えてください。

導入先で `./onboard.sh --status` は保存設定を確認し、`./onboard.sh --resume` は設定を再開します。実機確認とは別です。ハードウェアツールとサーバーを同時に実行しないでください。動作ツールは記録開始時にサーボを中央へ動かす場合があります。設定済みピンと安全な角度のみを使用し、個別速度は数値角度に付けます（`21:45F`、`21:XF` は不可）。

`config.json`（Gemini キーを含む場合があります）、ngrok 認証情報、校正ファイルを公開しないでください。料金・割り当て・利用可否はアカウントやモデルに依存します。Pi0 の操作画面にはログイン保護がなく、暗号化トンネルもアプリの認証を追加しません。信頼できるネットワークだけで使ってください。

詳細：[導入ガイド](InstallationGuide.md)、[開発ガイド](DevelopmentGuide.md)、[開発履歴](DevelopmentLog.md)。

<div align="center">

AI ロボティクス教育のために ❤️ を込めて作られました

</div>

---
---

<!-- 繁體中文 -->

# 繁體中文

更換模型：執行 `uv run ninja_core config select-model` 或 `./onboard.sh --step ai_model`，選擇 Google、OpenAI、Anthropic 或 Ollama Cloud，私下輸入 API 金鑰並驗證模型，然後手動重新啟動代理。Pi0 僅使用雲端推論；安裝程式會安裝 Ollama CLI，不下載本機模型或啟動守護程序，解壓暫存需 2 GB 可用空間。網頁麥克風輸入使用瀏覽器語音辨識，可搭配所有模型供應商；音訊檔上傳需要支援的 Gemini 模型。雲端呼叫可能產生費用。

## 1. 什麼是 NinjaRobotPi0？

**NinjaRobotPi0** 是一個以 **Raspberry Pi Zero 2 W**（一個口香糖大小的迷你電腦）為核心的開源教育機器人。它整合了伺服馬達（動作）、LCD 顯示螢幕（機器人的臉）、蜂鳴器（音效與旋律）、距離感測器、Google Gemini AI 對話、藍牙低功耗（BLE）以及瀏覽器控制介面——全部濃縮在一個小巧的套件中。

無論你想組裝輪型車、人形機器人或蜘蛛機器人，NinjaRobotPi0 都能幫助你學習軟體、AI 和硬體如何協同運作。

### 它能做什麼？

- **移動與表達** — 內建動作庫讓機器人行走、揮手、跳舞。LCD 顯示動畫表情，蜂鳴器播放情感音效。
- **感測距離** — VL53L0X 雷射感測器以毫米為單位量測距離，偵測障礙物。
- **AI 對話** — 連接 Google Gemini API 金鑰後即可和 AI 聊天，AI 還能觸發機器人動作。
- **手機操控** — 用任何裝置的瀏覽器開啟 Home、Agent（AI 聊天）和 Help 頁面，支援英文、日文、繁體中文、簡體中文。
- **循序漸進學習** — 用引導式工具校準每個元件，再依自己的節奏探索 Python 套件和 Web 介面。

---

## 2. 快速開始指南

### 2.1 推薦硬體

| 元件 | 規格 | 備註 |
|---|---|---|
| **電腦** | Raspberry Pi Zero 2 W（含 GPIO 排針） | 機器人的大腦 |
| **作業系統** | Raspberry Pi OS 64-bit（Bookworm / Trixie） | Debian 系，不需桌面 |
| **儲存** | microSD 卡 16 GB 以上 | 預留空間給依賴套件和前端建置 |
| **Pi 電源** | 5 V micro-USB 電源 | 僅供 Pi 使用 |
| **伺服馬達** | 最多 8 個 SG90 / MG90S 微型伺服 | 依車輪/手臂/腿的需求 |
| **伺服電源** | 獨立 5 V 3 A+ 電源 | 不可經由 Pi 電源引腳供電 |
| **顯示螢幕** | ST7789V SPI LCD 240×320 | 機器人的臉 |
| **距離感測器** | VL53L0X（I2C） | 雷射測距 |
| **蜂鳴器** | 被動式蜂鳴器（3–5 V） | 音效與旋律 |

### 2.2 接線

關閉電源後再接線。伺服馬達使用獨立電源，伺服電源的接地線與 Pi 的接地線共用（共地）。

| 元件 | 接線位置 |
|---|---|
| 伺服信號線（最多 8 條） | GPIO 20–27 |
| ST7789V SPI 資料 | MOSI → GPIO 10、SCLK → GPIO 11、CE0 → GPIO 8 |
| ST7789V 控制 | DC → GPIO 14、RST → GPIO 15、背光 → GPIO 16 |
| VL53L0X | SDA → GPIO 2、SCL → GPIO 3 |
| 蜂鳴器 | 信號 → GPIO 17 |

> ⚠️ **安全：** 通電時切勿更改接線。

GPIO 數字是 **BCM 編號**，不是實體排針序號。GPIO 使用 **3.3 V 邏輯**，不可輸入 5 V；請確認模組供電與驅動電路。伺服電源需依合計堵轉電流選擇；SG90/MG90S 定位伺服不提供車輪連續旋轉。

### 2.3 OS 安裝

1. 從 [raspberrypi.com/software](https://www.raspberrypi.com/software/) 下載 **Raspberry Pi Imager**。
2. 將 **Raspberry Pi OS 64-bit** 寫入 microSD 卡。設定主機名、SSH、Wi-Fi、使用者名稱。
3. 插入 Pi 並開機，用 SSH 連線：
   ```bash
   ssh YOUR_USERNAME@ninjarobotpi0.local
   ```
4. 執行 `sudo raspi-config` 啟用 **I2C** 和 **SPI**；若顯示器使用 GPIO 14/15，停用佔用這些腳位的序列主控台與 UART，需要時重新開機。

### 2.4 安裝專案

```bash
curl -fsSL https://raw.githubusercontent.com/NinjaRoboticsEducation/NinjaRobotPi0/HEAD/install.sh | bash
```

以一般使用者執行，輸入 `INSTALL` 確認。看到 **Software installed** 後才檢查並啟動 pigpiod（安裝程式不會啟動它或設定其自動啟動）：

```bash
cd "$HOME/NinjaRobotPi0" &&
./install.sh --check &&

# 啟動 pigpio（GPIO 硬體控制必需）：
sudo systemctl start pigpiod

# 選用：設定 pigpiod 開機自動啟動：
sudo systemctl enable pigpiod
```

**自訂安裝資料夾：**

```bash
mkdir -p "$HOME/Projects"
curl -fsSL https://raw.githubusercontent.com/NinjaRoboticsEducation/NinjaRobotPi0/HEAD/install.sh | bash -s -- --install-dir "$HOME/Projects/NinjaRobotPi0"
```

> **重要：** 若使用自訂安裝資料夾，請將後續 `cd` 換成實際路徑。`pigpiod` 是伺服馬達、蜂鳴器等 GPIO 硬體控制的必要服務。

### 2.5 引導式初始設定

支撐好機器人後執行：

```bash
./onboard.sh
```

| 步驟 | 內容 |
|---|---|
| 1. 顯示螢幕 | GPIO 腳位設定、方向與亮度測試 |
| 2. 蜂鳴器 | 腳位設定、測試音播放 |
| 3. 伺服馬達 | 輸入 `READY` 後校準各伺服的範圍與中立點 |
| 4. 距離感測 | 確認與校準感測器讀數 |
| 5. 匯入設定 | 將設定匯入 `config.json` |
| 6. 名稱/類型 | 設定 BLE 名稱和機器人類型（`tire`/`humanoid`/`spider`） |
| 7. 選擇模型供應商 | 設定 Google / OpenAI / Anthropic / Ollama Cloud API 金鑰和模型 |
| 8. ngrok | 設定遠端存取權杖（選用） |

> ⚠️ **注意：** 伺服工具開啟時可能**立即移動**校準過的伺服馬達。請務必先支撐好機器人。

### 2.6 建立動作

```bash
.venv/bin/ninja_core movement-tool
```

個別移動伺服、記錄姿勢、播放動作序列。

**動作指令格式：**

```
[速度_]腳位:角度[速度][/腳位:角度[速度]...]
```

| 範例 | 動作內容 |
|---|---|
| `20:45` | 將 GPIO 20 以中速移動到 45° |
| `20:C` | 將 GPIO 20 移至中央（0°） |
| `S_20:45/21:-30` | 兩個伺服以慢速同步移動 |

**速度：** `F` = 快速、`M` = 中速（預設）、`S` = 慢速
**角度關鍵字：** `C` = 中央（0°）、`M` = 最小（−90°）、`X` = 最大（90°）

### 2.7 啟動伺服器與 Web 介面

伺服器會初始化硬體，可能將伺服移至中立位置。ngrok 提示可按 Enter 保留已儲存的權杖；輸入或更換權杖請使用精靈的隱藏輸入。略過 ngrok 設定仍會嘗試連線，並非僅限本機模式。

```bash
.venv/bin/ninja_core server
```

用瀏覽器開啟顯示的**本機 URL**（通常 `http://<Pi 位址>:8000`）。

| 頁面 | 功能 |
|---|---|
| **Home** | 機器人首頁、關機控制 |
| **Agent** | AI 聊天、表情、音效、動作 |
| **Help** | 使用指南、語言切換 |

---

### 2.8. 自動啟動（選用）

如果您希望機器人在開機時自動啟動，請按照以下步驟操作。

> [!IMPORTANT]
> **前提條件：** 確保您已完成所有先前步驟，包括硬體校準和 API 金鑰設定。在啟用自動啟動之前，機器人必須完全正常運作。
>
> **ngrok 要求：** 自動啟動會檢查是否已有權杖，若無則結束。權杖存在不代表有效，請先確認手動啟動成功。

#### 步驟1：安裝啟動服務

在專案根目錄以一般使用者執行。使用安裝程式的檢查工具選取相容的 uv，供服務設定使用：

```bash
NINJAROBOT_UV="$(python3 -B scripts/install_check.py --find-tool uv)" &&
PATH="$(dirname -- "$NINJAROBOT_UV"):$PATH" .venv/bin/ninja_utils install-startup
```

這將會：

1. 檢查您的系統是否準備就緒（config 存在、pigpiod 正在執行等）
2. 建立 systemd 服務檔案
3. 設定下次開機自動啟動，不會立即啟動機器人。既有服務使用 `uv run ninja_core server --autostart`，可能在啟動時同步 Python 依賴套件。

#### 步驟2：驗證

您可以檢查服務狀態；手動啟動或重新開機前，已啟用但顯示 inactive（未執行）是正常的：

```bash
.venv/bin/ninja_utils status-startup
```

#### 步驟3：重新啟動

重新啟動您的 Raspberry Pi：

```bash
sudo reboot
```

重新開機後再次檢查服務狀態，使用實際主機名稱或 IP 位址（例如 `http://ninjarobotpi0.local:8000`）。QR 碼只在顯示器和公開通道成功運作時顯示，啟動時間依環境而異。

> [!TIP]
> **關機：** 使用 Home 的電源滑桿並確認後，系統會嘗試播放表情、音效及設定的 `Poweroff` 動作，請支撐好機器人。OS 關機需要執行 `sudo shutdown` 的權限；失敗時可透過 SSH 執行 `sudo shutdown -h now`。確認 OS 已停止後再斷電，不能只以 LED 不閃爍判斷。

#### 移除自動啟動

如果您想停止機器人自動啟動：

```bash
.venv/bin/ninja_utils remove-startup
```

---

## 3. 檔案結構

```
NinjaRobotPi0/
├── ninja_core/               # 伺服器核心：HAL、動作、AI、Web
├── ninja_ble/                # BLE GATT 服務
├── ninja_utils/              # 共用介面與工具程式
├── ninja_webapp/             # React + Vite 前端
├── pi0servo/                 # 伺服馬達驅動程式
├── pi0disp/                  # LCD 顯示驅動程式
├── pi0buzzer/                # 蜂鳴器驅動程式
├── pi0vl53l0x/               # 距離感測器驅動程式
├── ninjarobot_pi0_Wiki/      # 專案 Wiki 知識庫
├── install.sh                # 一鍵安裝程式
├── onboard.sh                # 引導式設定精靈
└── config.json               # 機器人設定檔
```

---

## 4. 疑難排解

### 更新後無法啟動 `ninja_core`

`Failed to spawn` / `No such file or directory` 表示 CLI 啟動檔不存在，不是伺服器設定遭拒。舊版根專案與個別套件重複擁有相同啟動檔；此次修正移除重複，安裝程式會重建並檢查五個啟動檔。先安全停止正在執行的機器人（可能執行 Poweroff），再於含修正的資料夾以一般使用者執行：

```bash
env -u UV_PROJECT_ENVIRONMENT -u UV_PROJECT uv sync --locked --inexact --no-dev --reinstall-package ninja-core --reinstall-package pi0servo --reinstall-package pi0disp --reinstall-package pi0buzzer --reinstall-package pi0vl53l0x
uv run --no-sync ninja_core --help
./install.sh --check
```

保留設定、校準及現有開發套件。其他工作目錄須等修正發布後先查看 `git status`，再執行 `git pull --ff-only`；Git 出錯時停止並保留本機修改。僅在說明指令成功且硬體準備完成後才執行 `uv run --no-sync ninja_core server`；啟動可能驅動硬體。

### 在安裝 Python 套件前停止

`Stop pigpiod ... first` / `Stop ninjarobot ... first` 代表在安裝依賴套件**前**停止。此時的 `PASS: software prerequisites` 只表示平台與路徑預檢通過，**Software installed** 才代表完成。缺少 `.venv/bin/ninja_core` 或套件中繼資料表示尚未安裝完整。

支撐好本體並切斷致動器電源，再停止手動執行的機器人。先停止機器人服務，再從既有資料夾重試：

```bash
sudo systemctl stop ninjarobot   # 僅限已安裝／執行此服務時
sudo systemctl stop pigpiod
cd "$HOME/NinjaRobotPi0" && ./install.sh && ./install.sh --check
```

保留校準與設定；再次失敗時記錄第一個錯誤。`--check` 不會修復環境。完成後，操作硬體前需重新啟動 pigpiod。若需先更新程式，使用 `git fetch origin HEAD && git merge --ff-only FETCH_HEAD`，Git 報錯就停止。安裝程式不會更新既有 Git 檔案。

| 問題 | 解決方法 |
|---|---|
| `curl` 回傳 404 | 請確認已發佈至官方儲存庫 |
| 不支援的平台 | 確認 Zero 2 W / aarch64 / Raspberry Pi OS 64-bit / Python 3.10+ / 一般使用者 |
| 顯示螢幕不亮 | 確認 SPI 已啟用：`sudo raspi-config` → SPI |
| 伺服馬達不動 | 確認 `pigpiod` 正在執行：`sudo systemctl status pigpiod`。抬起輪子重新校準 |
| 連接埠 8000 被佔用 | 停止已執行的伺服器後再啟動 |
| Gemini 設定失敗 | 確認網路連線與 API 金鑰。重試：`./onboard.sh --step gemini` |

---

## 5. 附錄

### 附錄 A：Google Gemini API 金鑰

1. 前往 [Google AI Studio](https://aistudio.google.com/) 並登入。
2. 點選 **Get API key** → **Create API key**。
3. 選擇或建立專案，確認模型可用性、配額與計費設定。
4. 複製產生的金鑰，在初始設定精靈的 Gemini 步驟中貼上。

變更金鑰：`./onboard.sh --step gemini`

> **注意：** 免費方案有使用限制。詳情請參閱 [Google AI 定價頁面](https://ai.google.dev/gemini-api/docs/pricing)。

### 附錄 B：ngrok 帳號設定

1. 前往 [ngrok.com](https://ngrok.com/) 註冊免費帳號。
2. 在儀表板的 **Your Authtoken** 複製權杖。
3. 在初始設定精靈的 ngrok 步驟中貼上。

變更權杖：`./onboard.sh --step ngrok`

> ⚠️ 切勿與他人分享 ngrok 公開 URL。知道 URL 的人可以操控你的機器人。

---

### 附錄 C：相容性與檢查參考

Bookworm/Trixie 64-bit 是參考環境，不是 OS 代號白名單。需使用 Zero 2 W、Linux `aarch64`、Debian 系 Raspberry Pi OS、一般使用者及 Python 3.10+。Node 需為 20.x 的 20.19+ 或 >=22.12.0；uv 只檢查必要指令能力，不要求固定版本。軟體檢查通過不代表實機驗收完成。

自訂安裝路徑必須是尚不存在的絕對路徑，先建立其父資料夾。安裝時不要加 `sudo`。請將 `YOUR_USERNAME` 與主機名稱換成 Imager 中設定的值。

在安裝目錄執行 `./onboard.sh --status` 檢查已儲存的設定，`./onboard.sh --resume` 繼續設定；這不等於實機驗證。勿同時執行硬體工具與伺服器。動作工具開始錄製時可能將伺服移至中立位置；只使用已設定的腳位和安全角度。個別速度後綴需接在數字角度後（`21:45F`，不可用 `21:XF`）。

保護 `config.json`（可能含 Gemini 金鑰）、ngrok 憑證與校準檔案，切勿公開。費率、配額與可用性依帳號及模型而異。Pi0 控制介面沒有使用者登入保護；加密通道不會增加應用程式驗證，請只在可信任網路使用。

詳細資料：[安裝指南](InstallationGuide.md)、[開發指南](DevelopmentGuide.md)、[開發紀錄](DevelopmentLog.md)。

<div align="center">

以 ❤️ 為 AI 機器人教育而製作

</div>

---
---

<!-- 简体中文 -->

# 简体中文

更换模型：运行 `uv run ninja_core config select-model` 或 `./onboard.sh --step ai_model`，选择 Google、OpenAI、Anthropic 或 Ollama Cloud，私下输入 API 密钥并验证模型，然后手动重启代理。Pi0 仅使用云端推理；安装程序会安装 Ollama CLI，不下载本地模型或启动守护进程，解压临时文件需要 2 GB 可用空间。网页麦克风输入使用浏览器语音识别，可搭配所有模型提供商；音频文件上传需要受支持的 Gemini 模型。云端调用可能产生费用。

## 1. 什么是 NinjaRobotPi0？

**NinjaRobotPi0** 是一个以 **Raspberry Pi Zero 2 W**（一个口香糖大小的迷你电脑）为核心的开源教育机器人。它集成了舵机（动作）、LCD 显示屏（机器人的脸）、蜂鸣器（音效与旋律）、距离传感器、Google Gemini AI 对话、蓝牙低功耗（BLE）以及浏览器控制界面——全部浓缩在一个小巧的套件中。

无论你想组装轮式车、人形机器人还是蜘蛛机器人，NinjaRobotPi0 都能帮助你学习软件、AI 和硬件如何协同工作。

### 它能做什么？

- **移动与表达** — 内置动作库让机器人行走、挥手、跳舞。LCD 显示动画表情，蜂鸣器播放情感音效。
- **感测距离** — VL53L0X 激光传感器以毫米为单位测量距离，检测障碍物。
- **AI 对话** — 连接 Google Gemini API 密钥后即可和 AI 聊天，AI 还能触发机器人动作。
- **手机操控** — 用任何设备的浏览器打开 Home、Agent（AI 聊天）和 Help 页面，支持英文、日文、繁体中文、简体中文。
- **循序渐进学习** — 用引导式工具校准每个组件，再按自己的节奏探索 Python 包和 Web 界面。

---

## 2. 快速开始指南

### 2.1 推荐硬件

| 组件 | 规格 | 备注 |
|---|---|---|
| **计算机** | Raspberry Pi Zero 2 W（带 GPIO 排针） | 机器人的大脑 |
| **操作系统** | Raspberry Pi OS 64-bit（Bookworm / Trixie） | Debian 系，不需桌面 |
| **存储** | microSD 卡 16 GB 以上 | 预留空间给依赖包和前端构建 |
| **Pi 电源** | 5 V micro-USB 电源 | 仅供 Pi 使用 |
| **舵机** | 最多 8 个 SG90 / MG90S 微型舵机 | 按车轮/手臂/腿的需求选配 |
| **舵机电源** | 独立 5 V 3 A+ 电源 | 不可通过 Pi 电源引脚供电 |
| **显示屏** | ST7789V SPI LCD 240×320 | 机器人的脸 |
| **距离传感器** | VL53L0X（I2C） | 激光测距 |
| **蜂鸣器** | 无源蜂鸣器（3–5 V） | 音效与旋律 |

### 2.2 接线

断电后再接线。舵机使用独立电源，舵机电源的接地线与 Pi 的接地线共用（共地）。

| 组件 | 接线位置 |
|---|---|
| 舵机信号线（最多 8 条） | GPIO 20–27 |
| ST7789V SPI 数据 | MOSI → GPIO 10、SCLK → GPIO 11、CE0 → GPIO 8 |
| ST7789V 控制 | DC → GPIO 14、RST → GPIO 15、背光 → GPIO 16 |
| VL53L0X | SDA → GPIO 2、SCL → GPIO 3 |
| 蜂鸣器 | 信号 → GPIO 17 |

> ⚠️ **安全：** 通电时切勿更改接线。

GPIO 数字是 **BCM 编号**，不是物理排针序号。GPIO 使用 **3.3 V 逻辑**，不可输入 5 V；请确认模块供电与驱动电路。舵机电源应按总堵转电流选择；SG90/MG90S 位置舵机不提供车轮连续旋转。

### 2.3 OS 安装

1. 从 [raspberrypi.com/software](https://www.raspberrypi.com/software/) 下载 **Raspberry Pi Imager**。
2. 将 **Raspberry Pi OS 64-bit** 写入 microSD 卡。设置主机名、SSH、Wi-Fi、用户名。
3. 插入 Pi 并开机，用 SSH 连接：
   ```bash
   ssh YOUR_USERNAME@ninjarobotpi0.local
   ```
4. 运行 `sudo raspi-config` 启用 **I2C** 和 **SPI**；若显示屏使用 GPIO 14/15，禁用占用这些引脚的串口控制台和 UART，需要时重启。

### 2.4 安装项目

```bash
curl -fsSL https://raw.githubusercontent.com/NinjaRoboticsEducation/NinjaRobotPi0/HEAD/install.sh | bash
```

以普通用户运行，输入 `INSTALL` 确认。看到 **Software installed** 后再检查并启动 pigpiod（安装程序不会启动它或设置其自启动）：

```bash
cd "$HOME/NinjaRobotPi0" &&
./install.sh --check &&

# 启动 pigpio（GPIO 硬件控制必需）：
sudo systemctl start pigpiod

# 可选：设置 pigpiod 开机自启动：
sudo systemctl enable pigpiod
```

**自定义安装文件夹：**

```bash
mkdir -p "$HOME/Projects"
curl -fsSL https://raw.githubusercontent.com/NinjaRoboticsEducation/NinjaRobotPi0/HEAD/install.sh | bash -s -- --install-dir "$HOME/Projects/NinjaRobotPi0"
```

> **重要：** 若选择自定义安装文件夹，请将后续 `cd` 换成实际路径。`pigpiod` 是舵机、蜂鸣器等 GPIO 硬件控制的必要服务。

### 2.5 引导式初始设置

支撑好机器人后运行：

```bash
./onboard.sh
```

| 步骤 | 内容 |
|---|---|
| 1. 显示屏 | GPIO 引脚设置、方向与亮度测试 |
| 2. 蜂鸣器 | 引脚设置、测试音播放 |
| 3. 舵机 | 输入 `READY` 后校准各舵机的范围与中立点 |
| 4. 距离传感 | 确认与校准传感器读数 |
| 5. 导入设置 | 将设置导入 `config.json` |
| 6. 名称/类型 | 设置 BLE 名称和机器人类型（`tire`/`humanoid`/`spider`） |
| 7. 选择模型提供商 | 设置 Google / OpenAI / Anthropic / Ollama Cloud API 密钥和模型 |
| 8. ngrok | 设置远程访问令牌（可选） |

> ⚠️ **注意：** 舵机工具打开时可能**立即移动**校准过的舵机。请务必先支撑好机器人。

### 2.6 创建动作

```bash
.venv/bin/ninja_core movement-tool
```

单独移动舵机、记录姿势、播放动作序列。

**动作命令格式：**

```
[速度_]引脚:角度[速度][/引脚:角度[速度]...]
```

| 示例 | 动作内容 |
|---|---|
| `20:45` | 将 GPIO 20 以中速移至 45° |
| `20:C` | 将 GPIO 20 移至中央（0°） |
| `S_20:45/21:-30` | 两个舵机以慢速同步移动 |

**速度：** `F` = 快速、`M` = 中速（默认）、`S` = 慢速
**角度关键字：** `C` = 中央（0°）、`M` = 最小（−90°）、`X` = 最大（90°）

### 2.7 启动服务器与 Web 界面

服务器会初始化硬件，可能将舵机移至中立位置。ngrok 提示可按 Enter 保留已保存的令牌；输入或更换令牌请使用向导的隐藏输入。跳过 ngrok 设置仍会尝试连接，并非仅限本地模式。

```bash
.venv/bin/ninja_core server
```

用浏览器打开显示的**本地 URL**（通常 `http://<Pi 地址>:8000`）。

| 页面 | 功能 |
|---|---|
| **Home** | 机器人首页、关机控制 |
| **Agent** | AI 聊天、表情、音效、动作 |
| **Help** | 使用指南、语言切换 |

---

### 2.8 自动启动（可选）

完成硬件校准、API 密钥设置并确认手动运行正常后，才启用自动启动。
自启动会检查 ngrok 令牌是否存在，若无则退出；存在不代表有效，请先手动验证。

#### 步骤 1：安装启动服务

在项目根目录以普通用户运行。使用安装程序的检查工具选择兼容的 uv，供服务配置使用：

```bash
NINJAROBOT_UV="$(python3 -B scripts/install_check.py --find-tool uv)" &&
PATH="$(dirname -- "$NINJAROBOT_UV"):$PATH" .venv/bin/ninja_utils install-startup
```

该工具检查 `config.json`、pigpiod、ninja_core 和 uv，创建并启用 `ninjarobot.service`，但不会立即启动机器人。
现有服务使用 `uv run ninja_core server --autostart`，可能在启动时同步 Python 依赖包。

#### 步骤 2：查看状态

手动启动或重启前，已启用但显示 inactive（未运行）是正常的。

```bash
.venv/bin/ninja_utils status-startup
```

#### 步骤 3：重启

```bash
sudo reboot
```

重启后再次检查状态，使用实际主机名或 IP 地址（例如 `http://ninjarobotpi0.local:8000`）。
二维码仅在显示屏和公开隧道成功工作时显示，启动时间因环境而异。

> **关机：** 使用 Home 的电源滑块并确认后，系统会尝试播放表情、音效及配置的 `Poweroff` 动作，请支撑好机器人。OS 关机需要执行 `sudo shutdown` 的权限；失败时可通过 SSH 执行 `sudo shutdown -h now`。确认 OS 已停止后再断电，不能只凭 LED 不闪烁判断。

#### 移除自启动

```bash
.venv/bin/ninja_utils remove-startup
```

---

## 3. 文件结构

```
NinjaRobotPi0/
├── ninja_core/               # 服务器核心：HAL、动作、AI、Web
├── ninja_ble/                # BLE GATT 服务
├── ninja_utils/              # 共享接口与工具程序
├── ninja_webapp/             # React + Vite 前端
├── pi0servo/                 # 舵机驱动程序
├── pi0disp/                  # LCD 显示驱动程序
├── pi0buzzer/                # 蜂鸣器驱动程序
├── pi0vl53l0x/               # 距离传感器驱动程序
├── ninjarobot_pi0_Wiki/      # 项目 Wiki 知识库
├── install.sh                # 一键安装程序
├── onboard.sh                # 引导式设置向导
└── config.json               # 机器人配置文件
```

---

## 4. 故障排除

### 更新后无法启动 `ninja_core`

`Failed to spawn` / `No such file or directory` 表示 CLI 启动文件不存在，不是服务器配置遭拒。旧版根项目与各个包重复拥有相同启动文件；此次修正移除重复，安装程序会重建并检查五个启动文件。先安全停止正在运行的机器人（可能执行 Poweroff），再在包含修正的目录中以普通用户执行：

```bash
env -u UV_PROJECT_ENVIRONMENT -u UV_PROJECT uv sync --locked --inexact --no-dev --reinstall-package ninja-core --reinstall-package pi0servo --reinstall-package pi0disp --reinstall-package pi0buzzer --reinstall-package pi0vl53l0x
uv run --no-sync ninja_core --help
./install.sh --check
```

保留配置、校准及现有开发包。其他工作目录须等修正发布后先查看 `git status`，再执行 `git pull --ff-only`；Git 出错时停止并保留本机修改。仅在帮助命令成功且硬件准备完成后才运行 `uv run --no-sync ninja_core server`；启动可能驱动硬件。

### 在安装 Python 包之前停止

`Stop pigpiod ... first` / `Stop ninjarobot ... first` 表示在安装依赖包**之前**停止。此时的 `PASS: software prerequisites` 只表示平台及路径预检通过，**Software installed** 才代表完成。缺少 `.venv/bin/ninja_core` 或包元数据表示安装不完整。

支撑好机体并断开执行器电源，再停止手动运行的机器人。先停止机器人服务，再从现有文件夹重试：

```bash
sudo systemctl stop ninjarobot   # 仅在已安装／运行此服务时
sudo systemctl stop pigpiod
cd "$HOME/NinjaRobotPi0" && ./install.sh && ./install.sh --check
```

保留校准与配置；再次失败时记录第一个错误。`--check` 不会修复环境。完成后，使用硬件前需重新启动 pigpiod。若需先更新代码，使用 `git fetch origin HEAD && git merge --ff-only FETCH_HEAD`，Git 报错就停止。安装程序不会更新现有 Git 文件。

| 问题 | 解决方法 |
|---|---|
| `curl` 返回 404 | 请确认已发布至官方仓库 |
| 不支持的平台 | 确认 Zero 2 W / aarch64 / Raspberry Pi OS 64-bit / Python 3.10+ / 普通用户 |
| 显示屏不亮 | 确认 SPI 已启用：`sudo raspi-config` → SPI |
| 舵机不动 | 确认 `pigpiod` 正在运行：`sudo systemctl status pigpiod`。抬起轮子重新校准 |
| 端口 8000 被占用 | 停止已运行的服务器后再启动 |
| Gemini 设置失败 | 确认网络连接与 API 密钥。重试：`./onboard.sh --step gemini` |

---

## 5. 附录

### 附录 A：Google Gemini API 密钥

1. 前往 [Google AI Studio](https://aistudio.google.com/) 并登录。
2. 点击 **Get API key** → **Create API key**。
3. 选择或创建项目，确认模型可用性、配额及计费设置。
4. 复制生成的密钥，在初始设置向导的 Gemini 步骤中粘贴。

变更密钥：`./onboard.sh --step gemini`

> **注意：** 免费套餐有使用限制。详情请参阅 [Google AI 定价页面](https://ai.google.dev/gemini-api/docs/pricing)。

### 附录 B：ngrok 账号设置

1. 前往 [ngrok.com](https://ngrok.com/) 注册免费账号。
2. 在仪表盘的 **Your Authtoken** 复制令牌。
3. 在初始设置向导的 ngrok 步骤中粘贴。

变更令牌：`./onboard.sh --step ngrok`

> ⚠️ 切勿与他人分享 ngrok 公开 URL。知道 URL 的人可以操控你的机器人。

---

### 附录 C：兼容性与检查参考

Bookworm/Trixie 64-bit 是参考环境，不是 OS 代号白名单。需要 Zero 2 W、Linux `aarch64`、Debian 系 Raspberry Pi OS、普通用户及 Python 3.10+。Node 需为 20.x 的 20.19+ 或 >=22.12.0；uv 只检查必要命令能力，不要求固定版本。软件检查通过不代表实机验收完成。

自定义安装路径必须是尚不存在的绝对路径，先创建其父文件夹。安装时不要加 `sudo`。请将 `YOUR_USERNAME` 和主机名换成 Imager 中配置的值。

在安装目录运行 `./onboard.sh --status` 检查已保存的配置，`./onboard.sh --resume` 继续设置；这不等于实机验证。不要同时运行硬件工具和服务器。动作工具开始录制时可能将舵机移至中立位置；只使用已配置的引脚及安全角度。单独速度后缀需接在数字角度后（`21:45F`，不能用 `21:XF`）。

保护 `config.json`（可能包含 Gemini 密钥）、ngrok 凭据和校准文件，不要公开。费用、配额与可用性依账号及模型而异。Pi0 控制界面没有用户登录保护；加密隧道不会添加应用身份验证，请仅在可信网络使用。

详细资料：[安装指南](InstallationGuide.md)、[开发指南](DevelopmentGuide.md)、[开发记录](DevelopmentLog.md)。

<div align="center">

以 ❤️ 为 AI 机器人教育而制作

</div>

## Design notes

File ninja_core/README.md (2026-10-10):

# Ninja Core

This package contains the main application logic for NinjaRobotPi0. It integrates all the individual hardware libraries (`pi0servo`, `pi0buzzer`, etc.) into a cohesive system managed by a central configuration and a Hardware Abstraction Layer (HAL).

## Key Components

- **`hal.py` (Hardware Abstraction Layer):** Initializes and provides a single access point for all hardware drivers.
- **`config.py` (Configuration Manager):** Manages all robot settings from a central `config.json` file.
- **`dispatcher.py` (Command Dispatcher):** Central router for BLE and Web commands. Bridges all input sources.
- **`safe_executor.py` (Safe Execution - Phase 4):** Sandboxed environment for running user/AI-generated Python code safely. Blocks dangerous imports.
- **`ninja_coder.py` (AI Code Agent - Phase 4):** Gemini-powered agent for code generation, translation, and debugging.
- **`api_wrappers.py` (Robot API - Phase 4):** High-level wrappers (`RobotWrapper`, `BuzzerWrapper`, `DisplayWrapper`, `DistanceWrapper`) exposed as `robot` in the executor.
- **`movement_controller.py` (Motion System):** Executes complex, multi-servo movement sequences.
- **`facial_expressions.py`, `robot_sound.py`, `perception.py`:** High-level controllers for expressions, sounds, and sensing.
- **`web_server.py` (FastAPI Server):** Web interface with WebSocket support for real-time events (Phase 4: `/ws/events` added).

---

## V5 Changes

> [!IMPORTANT]
> As of V5, the HAL uses **dynamic driver loading** via `importlib` and validates drivers against ABCs.

### Key Changes:
- **Dynamic Loading**: Drivers are loaded from a registry, not hardcoded imports.
- **ABC Validation**: All drivers implement `Sensor` or `Actuator` interfaces.
- **Config Import**: Run `uv run ninja_core config import` to merge `servo.json` and `buzzer.json` into `config.json`.

### Driver Registry:
```python
DRIVER_REGISTRY = {
    "servos": {"module": "pi0servo.core.servo_group", "class": "ServoGroup"},  # V5.2.1
    "buzzer": {"module": "pi0buzzer.driver", "class": "MusicBuzzer"},
    "display": {"module": "pi0disp.disp.st7789v", "class": "ST7789V"},
    "distance_sensor": {"module": "pi0vl53l0x.driver", "class": "VL53L0X"},
}
```

---

## Built-in movement import and robot compatibility

Set `robot_type` with `ninja_core config set-type spider`, `humanoid`, or `wheel` (`wheel` normalizes to the existing `tire` value), then run `ninja_core config import`/`import-all`. Import seeds 19 `spider_*` waypoint movements plus `Poweroff` for Spider with GPIO20–27, or one all-configured-servo center movement named `home` for Wheel/Humanoid. Additional Wheel/Humanoid movements are deferred. Import never initializes hardware; default calibration created when `servo.json` is missing is not proof of physical calibration.

The installed `ninja_core/data/spider_otto.json` resource retains the original trajectory values, with runtime names adapted to the proposal. `movements` still maps names to step lists. Additive `movement_robot_types` scopes names and `builtin_movement_hashes` records last imported definitions so reimport/type changes preserve edits and custom collisions. Removed built-ins return on the next import. Type switching removes only unchanged managed sequences; incompatible edits remain stored but cannot run on the new type.

`MovementController.available_movement_names()` filters by robot type, valid waypoints and active driver channels. `execute_movement()` revalidates every waypoint before actuator writes and raises `MovementValidationError` for unknown/incompatible/malformed sequences. Known robot prefixes and copied legacy Spider trajectories (including the document's unprefixed `Poweroff`) remain guarded without metadata. Custom unscoped sequences require owner review of mechanical roles. Driver abort stops sequence advancement without a controller-issued recovery pose. Callback checks occur before/after blocking driver calls; immediate in-step callback interruption is not guaranteed. The controller lock serializes its own operations; independent Blockly/direct driver writers still use the existing runtime ownership mechanisms.

The CLI's execute menu, `GET /api/servos/movements` (`{"movements": [...]}`), and Ninja agent use filtered discovery. `POST /api/servos/movements/{name}/execute` returns 404 for unknown names, 422 for invalid/incompatible data before reclaiming runtime, and 409 on abort. Existing frontend routes/payloads remain compatible, and failed requests appear in the log. Text/audio agent plans use exact permitted names; an invalid native chain is rejected as a whole, retaining the response and logging the reason. Bounds are 32 native chain entries and 1–20 repetitions per entry. Saved Blockly actions remain a separate existing execution path.

Physical direction, clearance, load, timing and power still require manual Pi validation. `Poweroff` holds eight extreme targets and can execute during web/server shutdown. Opening a device tool can energize servos. See [validation](../docs/validation/BuiltinMovements-2026-10-09.md) before operation.

日本語: インポートで種類に合う動作を追加します。Wheel/Humanoid は `home` のみです。実行時にも種類と全ステップを検証します。物理的な校正・可動範囲・電源の確認は別途必要です。

繁體中文：匯入時加入對應類型的動作，Wheel/Humanoid 目前只有 `home`。執行時會再次驗證類型與所有步驟；仍須另外確認實際校正、活動範圍與電源。

## The Motion System (`movement_controller.py`)

The Motion System is responsible for all servo-based movements. It is composed of two main parts: the runtime `MovementController` class and the interactive `movement-tool` CLI.

### `MovementController` Class

This class is the runtime engine for executing pre-defined motion sequences.
- It is initialized with the HAL and `NinjaConfig` objects, removing the need for direct hardware or file system access.
- Its primary method, `execute_movement(movement_name)`, plays back a named sequence from the configuration.
- It uses **position-aware easing** for fluid multi-step motions:
  - **First step:** `ease_in_cubic` (accelerate only)
  - **Middle steps:** `linear` (constant velocity through waypoints)
  - **Last step:** `ease_out_cubic` (decelerate to stop)
- Arrival times depend on each servo's distance and calibration. Easing does not guarantee continuous physical momentum, balance, or source oscillator timing.

### `movement-tool` CLI

This is an interactive, command-line tool for developers to **calibrate, create, edit, and test** all servo-related functions. You can launch it by running `uv run ninja_core movement-tool` from the project root.

The tool presents a main menu with the following options:

- **1. Calibrate a Servo:** Launches the `pi0servo` calibration tool for a selected servo. This allows you to define the min, center, and max pulse widths. The new calibration is automatically imported into the application's main configuration when the tool is running.
- **2. Record new movement:** Starts the interactive recorder to create a new, named motion sequence step-by-step.
- **3. Modify existing movement:** Provides a menu to interactively edit, insert, or delete steps within a saved movement.
- **4. Execute a movement:** Plays back a saved movement, with options for looping.
- **5. Clear movement:** Deletes a saved movement from the configuration.
- **6. Exit:** Executes configured `Poweroff` (or configured `home` when Poweroff is absent), then shuts down HAL and saves `config.json`. No center command follows the exit pose. Type/waypoint validation remains enforced; a failed pose is logged and cleanup still runs. Keyboard interruption does not request an extra recovery movement. Shutdown releases PWM rather than holding the pose electrically.

### Browser session and reconnect lifecycle

The shared Home/Agent/Help layout opens `/ws/session` using the server-issued HttpOnly `ninja_web_session` cookie. Only one browser identity owns controls; same-cookie tabs share ownership. Another browser receives busy/4409. Every `/api/` request and `/ws/distance` or `/ws/events` socket requires that live primary session; inactive HTTP clients receive 423 and shutdown requests receive 503. Existing routes, payloads and auxiliary event messages are retained. Direct scripts using REST must obtain the cookie from HTML and keep `/ws/session` open; this is a connection-ownership contract, not authentication. BLE is unchanged and separately controlled.

Clients ping every 10 seconds; the server releases a dead connection after 35 seconds without input. The browser retries every 3 seconds. Final-tab disconnect cancels pending browser requests/greetings, stops Blockly/native output and restores an undistorted QR for the cached ngrok URL, or LAN URL if tunneling failed. RuntimePipeline suppresses automatic idle redraw while waiting for reconnect. Display failures cannot retain browser ownership; shutdown does not redraw QR over Poweroff. Request generations prevent work from a prior visit becoming authorized when the same browser reconnects. `center_all_servos(abort_check=None)` preserves existing default behavior while allowing web centering to check ownership inside the controller motion lock. Driver abort is still cooperative; no immediate physical stopping guarantee is made.

日本語：一つのブラウザー識別情報のみが操作できます。同じ Cookie のタブは共有し、最後の接続終了で再接続 QR を表示します。実機での停止タイミング・QR 読み取り確認は別途必要です。

繁體中文：僅允許一個瀏覽器身分操作；同 Cookie 分頁共用連線，最後一個連線結束後重新顯示 QR。仍須在實機驗證停止時機與 QR 可讀性。

See [lifecycle acceptance](../docs/validation/LifecycleRefinements-2026-10-10.md). The environment path stays `.venv`; its installer prompt is now `ninjarobotpi0`.

#### In-Depth Guide: Recording a New Movement

This feature allows you to define a sequence of positions for your servos, which are then saved as a single, named movement (e.g., "wave", "nod").

##### Command Input Rules

When recording, you define each step using a special command syntax:

| Rule | Description | Example |
| --- | --- | --- |
| **Basic Format** | A GPIO pin number and an angle, separated by a colon. Angles range from -90 to 90. | `17:45` |
| **Angle Keywords**  | Use keywords for common angles: `C` for Center (0°), `M` for Minimum (-90°), and `X` for Maximum (90°). | `17:C` |
| **Chaining** | Multiple servo movements in the same step are chained together with a `/`. | `17:45/22:-30` |
| **Speed Prefix** | Set the speed for a step with a prefix: `S_` (Slow), `M_` (Medium), or `F_` (Fast). Medium is the default. | `S_17:90/22:90` |
| **Auto-Completion** | **(Crucial Rule)** If a servo isn't specified in a command, it automatically holds its position from the *previous* step. This is the key to creating smooth, continuous motions. | If step 1 is `17:45` and step 2 is `22:30`, servo 17 remains at 45° during step 2. |

---

## Testing the Core Components

This guide assumes you are in the root directory of the `NinjaRobotPi0` project and have already installed all dependencies.

### Prerequisites

1.  **pigpio Daemon:** Before running any test, ensure the `pigpio` service is running.
    ```bash
    sudo pigpiod
    ```
2.  **Initial Configuration:** If you have not yet created the master `config.json`, run the import command at least once.
    ```bash
    uv run ninja_core config import-all
    ```

### Step 1: Calibrate and Test the Motion System

This workflow demonstrates the seamless integration of the calibration and movement tools.

1.  **Launch the Movement Tool:**
    ```bash
    uv run ninja_core movement-tool
    ```

2.  **Calibrate a Servo:**
    - Select option **1** to "Calibrate a Servo."
    - Choose the servo pin you wish to calibrate from the list.
    - The `pi0servo` calibration interface will launch. Follow the on-screen instructions (`h` for help) to set the Min, Center, and Max positions.
    - Press `q` to quit the calibration tool.
    - The `movement-tool` will automatically import the new settings and re-initialize the hardware.

3.  **Record a Movement:**
    - Select option **2** to "Record new movement."
    - Create a simple movement (e.g., `17:45`, confirm, then `17:C`, finish) and name it `test_wave`.

4.  **Execute the Movement:**
    - Select option **4** to "Execute a movement."
    - Choose the `test_wave` movement and loop it once.
    - **Expected Result:** The servo will smoothly move to its 45-degree position and back, respecting the calibration you just set.

5.  **Exit:** Select option **6** to exit. All your new calibration and movement data will be saved to `config.json`.

### Step 2: Test Other Core Components

You can test other hardware functionalities using the pre-made test scripts in the project root:

- **Test HAL (Servos and Buzzer):**
  ```bash
  uv run python test_hal.py
  ```
- **Test Display System:**
  ```bash
  uv run python test_facial_expressions.py
  ```
- **Test Sound System:**
  ```bash
  uv run python test_robot_sound.py
  ```
- **Test Perception System:**
  ```bash
-   **Test HAL (Servos and Buzzer):**
    ```bash
    uv run python test_hal.py
    ```
-   **Test Display System:**
    ```bash
    uv run python test_facial_expressions.py
    ```
-   **Test Sound System:**
    ```bash
    uv run python test_robot_sound.py
    ```
-   **Test Perception System:**
    ```bash
    uv run python test_perception.py
    ```

This confirms that all `ninja_core` systems are successfully communicating with and controlling the hardware.

### Step 3: Test the AI Agent

The AI Agent allows you to control the robot using natural language.

#### 3.1. Setup Google Gemini API Key and Model

1.  **Create an API Key:**
    -   Go to [Google AI Studio](https://aistudio.google.com/).
    -   Click on "Get API key" -> "Create API key".
    -   Copy the generated key.

2.  **Set the Key in NinjaRobot:**
    ```bash
    uv run ninja_core config set-key gemini YOUR_ACTUAL_API_KEY_HERE
    ```

    NinjaRobot queries Google's model catalog with the supplied key and lists Gemini models that support agent content generation. After you select a numbered model, NinjaRobot runs a bounded minimal generation request and saves the API key/model only if that request succeeds. Validation can take up to 60 seconds for a thinking model. A failed lookup, non-responsive model, or cancelled prompt leaves the existing Gemini configuration unchanged.

    The guided `uv run ninja_core init-tool` option performs the same model-selection flow while hiding the entered API key.

    Gemini 3 models use a bounded REST compatibility path with low thinking because the installed legacy Python SDK cannot configure their current thinking controls. A normal agent request may still take several seconds. The chat and server consoles show the configured model and return a visible error if the model exceeds the request timeout.

#### 3.2. Setup ngrok (For Remote Access)

To access the web server from outside your local network, you need an ngrok account.

1.  **Create an Account:**
    -   Go to [ngrok.com](https://ngrok.com/) and sign up for a free account.

2.  **Get Your Authtoken:**
    -   Go to your [ngrok Dashboard](https://dashboard.ngrok.com/get-started/your-authtoken).
    -   Copy your Authtoken.

3.  **Configure NinjaRobot:**
    -   When you run `uv run ninja_core server` for the first time, you will be prompted to enter this token.
    -   `uv run ninja_core server` - Start the web interface (interactive mode)
    -   `uv run ninja_core server --autostart` - Start in non-interactive mode (for systemd)
    -   Alternatively, you can set it manually via the ngrok CLI if installed, but the server prompt is the easiest method.

#### 3.3. Run the Interactive Chat
    This command initializes the robot and the AI agent, allowing you to type commands.
    ```bash
    uv run ninja_core chat
    ```

#### 3.4. Test Capabilities
    -   **Nuance:** Type "I am feeling joyful." -> Robot should show a happy face.
    -   **Multilingual:** Type "こんにちは" (Konnichiwa). -> Robot should reply in Japanese.
    -   **Search:** Type "What is the weather in Tokyo?" -> Robot should search and answer.
    -   **Auto-Emotion:** Type "Tell me a joke." -> Robot should speak (show speaking face) while answering.
    -   **Movement:** Type "Do a wave." (if you recorded a 'wave' movement). -> Robot should execute the movement.

### Step 4: Test Web Server & Remote Access

The Web Server provides a user-friendly interface for controlling the robot from any device on the network or over the internet.

1.  **Start the Server:**
    ```bash
    uv run ninja_core server
    ```
    - The robot will initialize all hardware.
    - It will attempt to start an `ngrok` tunnel automatically.
    - **Check the Display:** The robot's LCD screen should display a **QR Code**.

2.  **Connect to the Interface:**
    - **Option A (Mobile/Remote):** Scan the QR code on the robot's screen with your phone.
    - **Option B (Local Network):** Open a browser on your computer and go to `http://<robot-ip>:8000` (The IP is printed in the terminal).

3.  **Test Web Features:**
    - **AI Chat & Voice Input:**
        - **Text Chat:** Type a message in the input box and click **Send**.
        - **Voice Input:** Select your language (English, 日本語, 繁體中文, 简体中文), click the  **`ninja_agent.py`** - AI Agent
  - Google Gemini integration for NLP
  - Semantic understanding and intent mapping
  - Auto-emotion generation
  - Action chaining (Movement, Faces, Sounds)
  - Multilingual support (EN/JP/ZH-TW/ZH-CN)he robot will detect the selected language and respond in the same language (including distinguishing between Traditional and Simplified Chinese).
    - **Servo Movements:** Select a movement from the dropdown and click **Execute**.
    - **Facial Expressions:** Select an expression and click **Show**.
    - **Sounds:** Select an emotion sound and click **Play**.
    - **Distance Sensor**: Verify that the distance reading updates in real-time (every ~200ms).
    - **System Controls**: Use the **Power Off Robot** button to safely shut down the Raspberry Pi.

4.  **Test Obstacle Avoidance (Safety):**
    - While a movement is executing (e.g., a long sequence), place your hand in front of the sensor (< 50mm).
    - **Expected Result:** The robot should **immediately stop**, display a "scary" face, play a warning sound, and the web interface should show an error or stop notification.

## Cloud model selection

Use `uv run ninja_core config select-model`, init-tool option 1, or onboarding step 7 to select Google, OpenAI, Anthropic or Ollama Cloud using a hidden API key and a validated live model. Restart an already-running agent deliberately to apply a CLI selection. Pi0 uses cloud inference only; voice is enabled only for supported Google models. Read the [detailed implementation source](../ninjarobot_pi0_Wiki/raw/notes/ninjarobotpi0/2026-10-10-model-adapter/ModelAdapterImplementation.md) for private credentials, migration and manual validation.

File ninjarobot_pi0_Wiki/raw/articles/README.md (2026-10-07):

# NinjaRobotPi0

Official repository: [NinjaRoboticsEducation/NinjaRobotPi0](https://github.com/NinjaRoboticsEducation/NinjaRobotPi0).

This repository starts from the existing NinjaRobotV5 working snapshot, published with fresh Git history on 2026-10-07. Python package names, versions, robot functions, and runtime code are retained. GitHub documentation links use `HEAD` to follow the repository default branch.

<div align="center">

NinjaRobot Logo

**The Next-Generation AI-Powered Educational Robot Platform**






[English](#english) | [日本語](#日本語) | [繁體中文](#繁體中文)

</div>

---

# English

## 🎯 Project Overview

**NinjaRobotPi0** is an advanced, modular AI robot platform designed for Research and STEAM Education. Built on the Raspberry Pi Zero 2W, it combines cutting-edge AI capabilities with an intuitive web interface, making robotics accessible to learners of all ages.

Unlike traditional educational robots, NinjaRobot features an **Agentic AI** powered by Google Gemini that can understand natural language, execute commands, and even generate code to learn new behaviors autonomously.

## 🤖 Robot Specifications

### Hardware

| Component | Specification |
|---|---|
| **Brain** | Raspberry Pi Zero 2W (Quad-core ARM Cortex-A53, 512MB RAM) |
| **Display** | 2.0" ST7789V IPS LCD (240×320 pixels) |
| **Distance Sensor** | VL53L0X Time-of-Flight (up to 2m range) |
| **Sound** | Passive Buzzer (GPIO 17) |
| **Movement** | 8× Servo Motors (GPIO 20-27) |
| **Connectivity** | WiFi 802.11n, Bluetooth 4.2 LE |

### Software Stack

| Layer | Technology |
|---|---|
| **Backend** | FastAPI + Uvicorn |
| **AI Agent** | Google Gemini (user-selected available model) |
| **Frontend** | React 18 + Vite + react-i18next |
| **BLE Service** | bless (GATT Server) |
| **Hardware Control** | pigpio + Custom Drivers |

## ✨ Key Features

### 🧠 Agentic AI
- **Natural Language Understanding**: Chat with your robot in English, Japanese, or Chinese
- **Validated Model Selection**: Discover models available to your Gemini API key and save a model only after a bounded generation check succeeds
- **Gemini 3 Compatibility**: Use low-thinking REST generation with a 60-second bound when the legacy Python SDK cannot express current Gemini 3 thinking controls
- **Action Planning**: AI automatically translates requests into robot actions
- **Saved Blockly Actions**: Replay complete Code IDE actions saved over Bluetooth from the robot's local action library
- **Reliable BLE Save Status**: Code IDE saves are confirmed by robot-cached request status, so missed browser notifications do not look like failed uploads
- **Code Generation**: AI can write Python code to create new robot behaviors
- **Voice Input**: Speak commands using your device's microphone

### 📱 Modern Web Interface
- **Mobile-First Design**: Optimized for smartphones and tablets
- **Real-Time Feedback**: WebSocket-powered distance sensor display
- **Hardware Controls**: Trigger expressions, sounds, and movements
- **System Log Panel**: Monitor robot activities in real-time
- **Multi-Language UI**: Switch between EN, JA, ZH-TW, ZH-CN

### 🔗 Dual Connectivity
- **Local Wi-Fi**: Direct control via `http://ninjarobot.local:8000`
- **Bluetooth LE**: Zero-setup mobile app connection
- **BLE Request Recovery**: Dedicated command-status readback for robust Chrome/Raspberry Pi save confirmations
- **Remote Access**: ngrok tunnel for telepresence

### 🛡️ Safety First
- **Sandboxed Execution**: User/AI-generated code runs in a restricted environment
- **Emergency Stop**: Instant halt capability for all motors
- **Graceful Shutdown**: Safe power-off with "sleepy" animation (face, sound, and pose)
- **Shutdown Animation**: Robot displays sleepy face, plays sleepy sound, and moves to rest position before powering off

## 🚀 Quick Start

```bash
# Clone the repository
git clone https://github.com/NinjaRoboticsEducation/NinjaRobotPi0.git
cd NinjaRobotPi0

# Install dependencies (using uv)
uv pip install -e .

# Build the web interface
cd ninja_webapp && npm install && npm run build && cd ..

# Configure the Gemini key and select a validated model
# Option 1 hides the API key while you enter it.
uv run ninja_core init-tool

# Start the robot
uv run ninja_core server
```

Then open `http://ninjarobot.local:8000` in your browser!

During Gemini setup, NinjaRobot retrieves the models available to the supplied key and runs a minimal generation request before saving the key/model pair. Thinking-model validation can take up to 60 seconds. If lookup, validation, or selection fails, the previous Gemini configuration remains unchanged. The server console reports the configured model and returns a visible timeout instead of waiting indefinitely.

## 📚 Documentation

| Document | Description |
|---|---|
| [Installation Guide](InstallationGuide.md) | Hardware setup and software installation |
| [Development Guide](DevelopmentGuide.md) | API reference and architecture overview |
| [Project Upgrade Plan](ProjectUpgradePlan.md) | Project roadmap and phase details |
| [Development Log](DevelopmentLog.md) | Change history and version notes |
| [AI Development Protocol](AGENTS.md) | Cross-tool development, safety, validation, and wiki rules |
| [NinjaRobotPi0 Wiki](Wiki/NinjaRobotPi0_Wiki/README.md) | Local, source-traceable knowledge base for AI-assisted development |
| [Wiki Integration Workflow](WikiIntegrationWorkflowPlan.md) | Integration design, maintenance gates, and rollout checks |

## 📊 Current Status

**Version:** 5.3.0  
**Status:** Phase 5 Complete ✅ + All Hardware Libraries Rebuilt

All core features have been implemented and verified:
- ✅ Modular Hardware Abstraction Layer
- ✅ Dual Connectivity (Wi-Fi + BLE)
- ✅ Agentic AI with Action Planning
- ✅ Saved Blockly Action Library for Code IDE uploads
- ✅ Safe Code Execution Engine
- ✅ React Web Application
- ✅ pi0servo V1.0 (velocity-based motion, per-servo speed, easing curves)
- ✅ pi0vl53l0x V2.0 (thread-safe I2C, hardened init, CLI)
- ✅ pi0disp V2.0 (thread-safe SPI, delta rendering, PWM brightness)
- ✅ pi0buzzer V1.0 (non-blocking queue, emotion sounds, interactive TUI)

## 📄 License

This project is licensed under the **MIT License**.

**Copyright © 2026 Chihkuang Chang**

---

# 日本語

## 🎯 プロジェクト概要

**NinjaRobotPi0**は、研究およびSTEAM教育向けに設計された先進的なモジュール式AIロボットプラットフォームです。Raspberry Pi Zero 2Wをベースに構築され、最先端のAI機能と直感的なWebインターフェースを組み合わせ、あらゆる年齢の学習者がロボット工学にアクセスできるようにしています。

従来の教育用ロボットとは異なり、NinjaRobotはGoogle Geminiを搭載した**エージェント型AI**を特徴とし、自然言語を理解し、コマンドを実行し、さらには自律的に新しい動作を学習するためのコードを生成することができます。

## 🤖 ロボット仕様

### ハードウェア

| コンポーネント | 仕様 |
|---|---|
| **頭脳** | Raspberry Pi Zero 2W（クアッドコアARM Cortex-A53、512MB RAM） |
| **ディスプレイ** | 2.0インチ ST7789V IPS LCD（240×320ピクセル） |
| **距離センサー** | VL53L0X ToF（最大2m測定可能） |
| **音声** | パッシブブザー（GPIO 17） |
| **動作** | 8×サーボモーター（GPIO 20-27） |
| **接続** | WiFi 802.11n、Bluetooth 4.2 LE |

### ソフトウェアスタック

| レイヤー | 技術 |
|---|---|
| **バックエンド** | FastAPI + Uvicorn |
| **AIエージェント** | Google Gemini（利用可能なモデルをユーザーが選択） |
| **フロントエンド** | React 18 + Vite + react-i18next |
| **BLEサービス** | bless（GATTサーバー） |
| **ハードウェア制御** | pigpio + カスタムドライバー |

## ✨ 主な機能

### 🧠 エージェント型AI
- **自然言語理解**: 英語、日本語、中国語でロボットと会話
- **検証付きモデル選択**: Gemini APIキーで利用可能なモデルを取得し、時間制限付き生成テストに成功したモデルだけを保存
- **Gemini 3互換性**: 従来のPython SDKで現在の思考制御を指定できない場合、低思考レベルと60秒の上限を設定したREST生成を使用
- **アクションプランニング**: AIがリクエストを自動的にロボットのアクションに変換
- **保存済みBlocklyアクション**: Bluetooth経由で保存したCode IDEの完全な動作をローカルアクションライブラリから再生
- **コード生成**: AIが新しいロボットの動作を作成するPythonコードを記述
- **音声入力**: デバイスのマイクを使用してコマンドを話す

### 📱 モダンなWebインターフェース
- **モバイルファーストデザイン**: スマートフォンやタブレット向けに最適化
- **リアルタイムフィードバック**: WebSocket対応の距離センサー表示
- **ハードウェアコントロール**: 表情、音、動きをトリガー
- **システムログパネル**: ロボットの活動をリアルタイムで監視
- **多言語UI**: EN、JA、ZH-TW、ZH-CNで切り替え

### 🔗 デュアル接続
- **ローカルWi-Fi**: `http://ninjarobot.local:8000`経由で直接制御
- **Bluetooth LE**: セットアップ不要のモバイルアプリ接続
- **リモートアクセス**: テレプレゼンス用ngrokトンネル

### 🛡️ 安全第一
- **サンドボックス実行**: ユーザー/AI生成コードは制限された環境で実行
- **緊急停止**: すべてのモーターを即座に停止する機能
- **安全なシャットダウン**: 「眠い」アニメーション付きの安全な電源オフ（表情、音、姿勢）
- **シャットダウンアニメーション**: 電源オフ前に眠い顔を表示、眠い音を再生、休憩姿勢に移動

## 🚀 クイックスタート

```bash
# リポジトリをクローン
git clone https://github.com/NinjaRoboticsEducation/NinjaRobotPi0.git
cd NinjaRobotPi0

# 依存関係をインストール（uvを使用）
uv pip install -e .

# Webインターフェースをビルド
cd ninja_webapp && npm install && npm run build && cd ..

# Gemini APIキーを設定し、検証済みモデルを選択
# オプション1では入力中のAPIキーが非表示になります。
uv run ninja_core init-tool

# ロボットを起動
uv run ninja_core server
```

ブラウザで `http://ninjarobot.local:8000` を開いてください！

Geminiの設定時、NinjaRobotは入力したキーで利用可能なモデルを取得し、キーとモデルを保存する前に最小生成テストを実行します。思考モデルの検証には最大60秒かかる場合があります。取得、検証、または選択に失敗した場合、以前のGemini設定は変更されません。サーバーコンソールには設定中のモデルが表示され、無期限に待機する代わりに明確なタイムアウトが返されます。

## 📚 ドキュメント

| ドキュメント | 説明 |
|---|---|
| [インストールガイド](InstallationGuide.md) | ハードウェアセットアップとソフトウェアインストール |
| [開発ガイド](DevelopmentGuide.md) | APIリファレンスとアーキテクチャ概要 |
| [プロジェクトアップグレード計画](ProjectUpgradePlan.md) | プロジェクトロードマップとフェーズ詳細 |
| [開発ログ](DevelopmentLog.md) | 変更履歴とバージョンノート |
| [AI開発プロトコル](AGENTS.md) | AIツール共通の開発、安全、検証、Wiki運用ルール |
| [NinjaRobotPi0 Wiki](Wiki/NinjaRobotPi0_Wiki/README.md) | AI支援開発向けの出典追跡可能なローカル知識ベース |
| [Wiki統合ワークフロー](WikiIntegrationWorkflowPlan.md) | 統合設計、保守ゲート、導入確認 |

## 📊 現在のステータス

**バージョン:** 5.3.0  
**ステータス:** フェーズ5完了 ✅ + 全ハードウェアライブラリ再構築済み

すべてのコア機能が実装・検証されました：
- ✅ モジュール式ハードウェア抽象化レイヤー
- ✅ デュアル接続（Wi-Fi + BLE）
- ✅ アクションプランニング付きエージェント型AI
- ✅ Code IDEアップロード用の保存済みBlocklyアクションライブラリ
- ✅ 安全なコード実行エンジン
- ✅ React Webアプリケーション
- ✅ pi0servo V1.0（速度ベース制御、サーボ別速度、イージングカーブ）
- ✅ pi0vl53l0x V2.0（スレッドセーフI2C、堅牢な初期化、CLI）
- ✅ pi0disp V2.0（スレッドセーフSPI、デルタレンダリング、PWM輝度制御）
- ✅ pi0buzzer V1.0（ノンブロッキングキュー、感情サウンド、インタラクティブTUI）

## 📄 ライセンス

このプロジェクトは**MITライセンス**の下でライセンスされています。

**Copyright © 2026 Chihkuang Chang**

---

# 繁體中文

## 🎯 專案概述

**NinjaRobotPi0**是一個為研究與STEAM教育設計的先進模組化AI機器人平台。基於Raspberry Pi Zero 2W構建，結合尖端AI功能與直覺的網頁介面，讓各年齡層的學習者都能輕鬆接觸機器人技術。

與傳統教育機器人不同，NinjaRobot搭載由Google Gemini驅動的**代理式AI**，能夠理解自然語言、執行指令，甚至自主生成程式碼來學習新行為。

## 🤖 機器人規格

### 硬體

| 元件 | 規格 |
|---|---|
| **大腦** | Raspberry Pi Zero 2W（四核心 ARM Cortex-A53，512MB RAM） |
| **顯示器** | 2.0吋 ST7789V IPS LCD（240×320像素） |
| **距離感測器** | VL53L0X ToF（最遠2公尺） |
| **音效** | 被動蜂鳴器（GPIO 17） |
| **動作** | 8×伺服馬達（GPIO 20-27） |
| **連線** | WiFi 802.11n、藍牙 4.2 LE |

### 軟體架構

| 層級 | 技術 |
|---|---|
| **後端** | FastAPI + Uvicorn |
| **AI代理** | Google Gemini（由使用者選擇可用模型） |
| **前端** | React 18 + Vite + react-i18next |
| **BLE服務** | bless（GATT伺服器） |
| **硬體控制** | pigpio + 自訂驅動程式 |

## ✨ 主要功能

### 🧠 代理式AI
- **自然語言理解**：用英文、日文或中文與機器人對話
- **經驗證的模型選擇**：取得Gemini API金鑰可用的模型，並只在有時限的生成測試成功後儲存模型
- **Gemini 3相容性**：當舊版Python SDK無法設定目前的Gemini 3思考控制時，使用低思考等級與60秒上限的REST生成
- **動作規劃**：AI自動將請求轉換為機器人動作
- **已儲存Blockly動作**：可從本機動作庫重播經由藍牙儲存的完整Code IDE動作
- **程式碼生成**：AI能撰寫Python程式碼來創建新的機器人行為
- **語音輸入**：使用裝置麥克風說出指令

### 📱 現代化網頁介面
- **行動優先設計**：針對智慧型手機和平板優化
- **即時回饋**：WebSocket驅動的距離感測器顯示
- **硬體控制**：觸發表情、音效和動作
- **系統日誌面板**：即時監控機器人活動
- **多語言介面**：支援EN、JA、ZH-TW、ZH-CN切換

### 🔗 雙重連線
- **本地Wi-Fi**：透過`http://ninjarobot.local:8000`直接控制
- **藍牙LE**：免設定的行動應用程式連線
- **遠端存取**：ngrok通道實現遠端遙控

### 🛡️ 安全至上
- **沙盒執行**：使用者/AI生成的程式碼在受限環境中執行
- **緊急停止**：即時停止所有馬達的功能
- **安全關機**：透過「睏倦」動畫安全關閉電源（表情、音效和姿勢）
- **關機動畫**：電源關閉前顯示睡眠表情、播放睡眠音效並移動至休息姿勢

## 🚀 快速開始

```bash
# 複製儲存庫
git clone https://github.com/NinjaRoboticsEducation/NinjaRobotPi0.git
cd NinjaRobotPi0

# 安裝相依套件（使用uv）
uv pip install -e .

# 建置網頁介面
cd ninja_webapp && npm install && npm run build && cd ..

# 設定Gemini API金鑰並選擇經驗證的模型
# 選項1會在輸入時隱藏API金鑰。
uv run ninja_core init-tool

# 啟動機器人
uv run ninja_core server
```

然後在瀏覽器開啟 `http://ninjarobot.local:8000`！

設定Gemini時，NinjaRobot會取得此金鑰可用的模型，並在儲存金鑰與模型前執行最小生成測試。思考模型的驗證最多可能需要60秒。若取得、驗證或選擇失敗，先前的Gemini設定不會被變更。伺服器主控台會顯示目前設定的模型，並在逾時時回傳明確錯誤，而不是無限等待。

## 📚 文件

| 文件 | 說明 |
|---|---|
| [安裝指南](InstallationGuide.md) | 硬體設定與軟體安裝 |
| [開發指南](DevelopmentGuide.md) | API參考與架構概述 |
| [專案升級計畫](ProjectUpgradePlan.md) | 專案路線圖與階段詳情 |
| [開發日誌](DevelopmentLog.md) | 變更歷史與版本說明 |
| [AI 開發協定](AGENTS.md) | 跨工具開發、安全、驗證與 Wiki 維護規則 |
| [NinjaRobotPi0 Wiki](Wiki/NinjaRobotPi0_Wiki/README.md) | 供 AI 輔助開發使用、可追溯來源的本機知識庫 |
| [Wiki 整合工作流程](WikiIntegrationWorkflowPlan.md) | 整合設計、維護閘門與導入檢查 |

## 📊 目前狀態

**版本：** 5.3.0  
**狀態：** 第五階段完成 ✅ + 全硬體函式庫重建完成

所有核心功能已實作並驗證：
- ✅ 模組化硬體抽象層
- ✅ 雙重連線（Wi-Fi + BLE）
- ✅ 具動作規劃的代理式AI
- ✅ 支援Code IDE上傳的已儲存Blockly動作庫
- ✅ 安全程式碼執行引擎
- ✅ React網頁應用程式
- ✅ pi0servo V1.0（速度控制、獨立伺服速度、緩動曲線）
- ✅ pi0vl53l0x V2.0（線程安全I2C、強化初始化、CLI）
- ✅ pi0disp V2.0（線程安全SPI、差異渲染、PWM亮度控制）
- ✅ pi0buzzer V1.0（非阻塞佇列、情緒音效、互動式TUI）

## 📄 授權

本專案採用**MIT授權**。

**Copyright © 2026 Chihkuang Chang**

---

<div align="center">

Made with ❤️ for Education and Research

</div>

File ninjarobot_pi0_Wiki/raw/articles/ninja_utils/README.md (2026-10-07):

# ninja_utils

This library provides shared utilities for the NinjaRobotPi0 project, including:
- Centralized logging
- Non-blocking keyboard input
- Systemd service management for autostart

## Installation

To install this library in editable mode for development:

```bash
cd /path/to/your/NinjaRobotPi0/ninja_utils
uv pip install -e .
```

## CLI Commands

**`install-startup`**
- Installs the systemd service for automatic startup.
- Usage: `uv run ninja_utils install-startup`

**`remove-startup`**
- Removes the systemd service.
- Usage: `uv run ninja_utils remove-startup`

**`status-startup`**
- Checks the status of the service.
- Usage: `uv run ninja_utils status-startup`

## Usage

Refer to the `samples/sample.py` file for an example of how to use the utilities.

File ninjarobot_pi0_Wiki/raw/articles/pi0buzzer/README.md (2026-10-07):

# pi0buzzer 🎵

A non-blocking passive buzzer driver for Raspberry Pi with musical note support, emotion sounds, and an interactive testing tool.

**Part of the [NinjaRobotPi0](../README.md) platform.**

---

## Features

| Feature | Description |
|---|---|
| **Non-blocking playback** | All sounds play in a background thread — safe for asyncio |
| **Actuator ABC** | Implements `ninja_utils.Actuator` for plugin integration |
| **Musical notes** | C3–B7 note frequencies (5 octaves, 35 notes) |
| **14 emotion sounds** | happy, sad, exciting, angry, confusing, cry, embarrassing, idle, laughing, scary, shy, sleepy, speaking, surprising |
| **Volume control** | Adjustable PWM duty cycle (0–255) |
| **Interactive tool** | Menu-driven `buzzer-tool` TUI for testing |
| **Keyboard piano** | Play notes using keyboard keys in real-time |
| **Config manager** | JSON-based config with validation, export/import |
| **CLI commands** | Scriptable commands for automation |
| **Unit tested** | 61 tests with mocked pigpio |

---

## Architecture

```
pi0buzzer/
├── pyproject.toml
├── README.md
├── LICENSE
├── RebuildPlan.md
├── src/pi0buzzer/
│   ├── __init__.py              # Exports: Buzzer, MusicBuzzer
│   ├── __main__.py              # CLI entry point (click group)
│   ├── driver.py                # Compatibility shim (re-exports)
│   ├── notes.py                 # Note frequencies, emotion sounds, keyboard map
│   ├── core/
│   │   ├── driver.py            # Buzzer — Actuator ABC, queue worker
│   │   └── music.py             # MusicBuzzer — songs, emotions, piano
│   ├── config/
│   │   └── config_manager.py    # BuzzerConfigManager
│   └── cli/
│       └── buzzer_tool.py       # Interactive TUI
└── tests/
    ├── conftest.py              # Mock pigpio fixtures
    ├── test_driver.py           # 26 Buzzer tests
    ├── test_music.py            # 14 MusicBuzzer tests
    └── test_config.py           # 21 ConfigManager tests
```

---

## Installation

### Prerequisites

1. **Raspberry Pi** with Raspberry Pi OS (Bookworm or later)
2. **pigpio daemon** installed and running:
   ```bash
   sudo apt install pigpio
   sudo pigpiod
   ```
3. **Python 3.9+** installed

### Step 1: Clone the repository

```bash
git clone https://github.com/NinjaRoboticsEducation/NinjaRobotPi0.git
cd NinjaRobotPi0
```

### Step 2: Install with uv (recommended)

```bash
# Install uv if not already installed
curl -LsSf https://astral.sh/uv/install.sh | sh

# Install the workspace (all packages including pi0buzzer)
uv sync
```

### Step 3: Verify installation

```bash
uv run pi0buzzer --help
```

Expected output:
```
Usage: pi0buzzer [OPTIONS] COMMAND [ARGS]...

  pi0buzzer CLI tool.

Options:
  -C, --config-file TEXT  Path to config file (default: buzzer.json).
  --help                  Show this message and exit.

Commands:
  beep         Play a single tone.
  buzzer-tool  Launch the interactive buzzer tool (TUI).
  config       Configuration management (show/export/import).
  info         Show buzzer configuration and status.
  init         Initialize buzzer config with the given GPIO pin.
  play         Play a predefined emotion sound.
```

---

## Getting Started

### 1. Initialize the buzzer

Connect a passive buzzer to a GPIO pin (e.g., GPIO 17) and initialize:

```bash
uv run pi0buzzer init 17
```

This will:
- Save the pin configuration to `buzzer.json`
- Play a test beep to verify the connection

### 2. Play a tone

```bash
# Default: 440 Hz for 0.5 seconds
uv run pi0buzzer beep

# Custom frequency and duration
uv run pi0buzzer beep 880 1.0
```

### 3. Play an emotion sound

```bash
uv run pi0buzzer play happy
uv run pi0buzzer play sad
uv run pi0buzzer play exciting
```

Available emotions:
`angry`, `confusing`, `cry`, `embarrassing`, `exciting`, `happy`, `idle`, `laughing`, `scary`, `shy`, `sleepy`, `speaking`, `surprising`, `sad`

### 4. Check status

```bash
# Show configuration
uv run pi0buzzer info

# With hardware health check
uv run pi0buzzer info --health-check
```

### 5. Launch the interactive tool

```bash
uv run pi0buzzer buzzer-tool
```

This opens a menu-driven TUI:

```
╔══════════════════════════════════════════════════════════════╗
║               pi0buzzer Interactive Tool                    ║
╠══════════════════════════════════════════════════════════════╣
║  1. Init          - Set up buzzer pin & save config         ║
║  2. Beep          - Play a single tone (freq/duration)      ║
║  3. Play Emotion  - Play an emotion sound by name           ║
║  4. Play Music    - Interactive keyboard piano              ║
║  5. Play Song     - Play the demo melody                   ║
║  6. Volume        - Adjust buzzer volume                   ║
║  7. Info          - Show config & health check              ║
║  8. Config        - Show/export/import settings             ║
║  9. Exit                                                    ║
╚══════════════════════════════════════════════════════════════╝
```

---

## Configuration Management

### Show, export, and import config

```bash
# Show current config
uv run pi0buzzer config show

# Export to a file
uv run pi0buzzer config export ~/buzzer_backup.json

# Import from a file
uv run pi0buzzer config import ~/buzzer_backup.json
```

### Config file format (`buzzer.json`)

```json
{
  "pin": 17,
  "volume": 128
}
```

| Key | Type | Range | Default | Description |
|---|---|---|---|---|
| `pin` | int | 0–27 | 17 | BCM GPIO pin number |
| `volume` | int | 0–255 | 128 | PWM duty cycle (0=silent, 255=max) |

---

## Python API

### Standalone Usage

```python
from pi0buzzer import MusicBuzzer

# Using context manager (recommended)
with MusicBuzzer(pin=17) as buzzer:
    # Play a single tone
    buzzer.play_sound(440, 0.5)

    # Play a named note
    buzzer.play_note("C5", 0.3)

    # Play an emotion
    buzzer.play_emotion("happy")

    # Play a song
    buzzer.play_song([
        ("C4", 0.3), ("E4", 0.3), ("G4", 0.3), ("C5", 0.6),
    ])

    # Adjust volume
    buzzer.volume = 64  # 25%
```

### Manual lifecycle

```python
import pigpio
from pi0buzzer import MusicBuzzer

pi = pigpio.pi()
buzzer = MusicBuzzer(pin=17, pi=pi, volume=128)

try:
    buzzer.initialize()
    buzzer.play_emotion("exciting")
    import time; time.sleep(2.0)
finally:
    buzzer.off()
    pi.stop()
```

### Key Classes

| Class | Module | Description |
|---|---|---|
| `Buzzer` | `pi0buzzer.core.driver` | Base driver — Actuator ABC, queue worker |
| `MusicBuzzer` | `pi0buzzer.core.music` | Extended with notes, songs, emotions |
| `BuzzerConfigManager` | `pi0buzzer.config` | JSON config management |

### Key Methods

| Method | Class | Description |
|---|---|---|
| `initialize()` | Buzzer | Start background worker thread |
| `execute(cmd)` | Buzzer | Queue `{frequency, duration}` command |
| `play_sound(freq, dur)` | Buzzer | Play single tone (non-blocking) |
| `off()` | Buzzer | Stop and silence buzzer |
| `play_note(name, dur)` | MusicBuzzer | Play named note (e.g., "C5") |
| `play_song(song)` | MusicBuzzer | Queue a melody |
| `play_emotion(name)` | MusicBuzzer | Play emotion sound |
| `play_demo()` | MusicBuzzer | Play demo melody |
| `play_music()` | MusicBuzzer | Interactive keyboard piano |

---

## Testing

### Run unit tests

```bash
# From the workspace root
uv run --with pytest pytest pi0buzzer/tests/ -v
```

All 61 tests pass with **mocked pigpio** — no hardware required:

```
tests/test_config.py     — 21 passed (config load/save/validate/export/import)
tests/test_driver.py     — 26 passed (init, execute, volume, pause, off, context manager)
tests/test_music.py      — 14 passed (play_note, play_song, play_emotion, notes validation)
```

### Hardware testing (Raspberry Pi)

```bash
# 1. Start pigpio daemon
sudo pigpiod

# 2. Initialize with your buzzer pin
uv run pi0buzzer init 17

# 3. Run health check
uv run pi0buzzer info --health-check

# 4. Test with interactive tool
uv run pi0buzzer buzzer-tool
```

---

## Hardware Wiring

Connect a **passive buzzer** (not active) to your Raspberry Pi:

| Buzzer Pin | Raspberry Pi Pin |
|---|---|
| **+** (Signal) | GPIO 17 (or configured pin) |
| **−** (Ground) | GND |

> ⚠️ **Important**: Only passive buzzers produce different frequencies. Active buzzers emit a fixed tone regardless of PWM frequency.

---

## Keyboard Piano Key Map

When using `Play Music` mode (option 4 in `buzzer-tool`):

| Keys | Notes | Octave |
|---|---|---|
| `z x c v b n m` | C4 D4 E4 F4 G4 A4 B4 | Low (4) |
| `a s d f g h j` | C5 D5 E5 F5 G5 A5 B5 | Mid (5) |
| `q w e r t y u` | C6 D6 E6 F6 G6 A6 B6 | High (6) |

Type `quit` to exit piano mode.

---

## License

MIT License — © 2025 Chihkuang Chang

See [LICENSE](LICENSE) for full text.

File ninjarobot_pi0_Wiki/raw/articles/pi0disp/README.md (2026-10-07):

# pi0disp — ST7789V Display Driver

Thread-safe SPI driver for ST7789V-based displays with smart delta rendering and PWM brightness control.

## Features

- **Thread-safe SPI** — All SPI operations protected by `threading.Lock()`, safe for concurrent use with `AnimatedFaces` and `web_server.py`
- **Smart delta rendering** — Detects changed pixels via `PIL.ImageChops.difference()`, transmitting only the dirty region (~90% bandwidth savings for animations)
- **PWM brightness** — Smooth backlight control (0-100%) via `pigpio.set_PWM_dutycycle()`
- **Actuator ABC** — Implements `ninja_utils.Actuator` interface for seamless `ninja_core` HAL integration
- **Display profiles** — Pre-configured for ST7789V 2.8" IPS TFT and Waveshare 2.0" IPS LCD
- **Configuration Manager** — `display.json` with interactive setup wizard, CRUD operations, export/import
- **Multilingual text** — Scrolling marquee with bundled Noto fonts (English, Japanese, Traditional Chinese)
- **CLI tools** — 11 commands + interactive `display-tool` menu for standalone Raspberry Pi usage

## Supported Displays

| Display | Size | Resolution | Driver IC |
|---|---|---|---|
| ST7789V IPS TFT | 2.8 inch | 240×320 | ST7789V |
| Waveshare IPS LCD | 2.0 inch | 240×320 | ST7789V |

## Directory Structure

```
pi0disp/
├── pyproject.toml
├── README.md               ← This file
├── LICENSE                  # MIT License
├── tests/                   # Unit tests (54 tests, no hardware required)
│   ├── conftest.py          # Mock pigpio fixtures
│   ├── test_renderer.py     # ColorConverter, RegionOptimizer tests
│   ├── test_driver.py       # ST7789V driver tests (thread safety, delta rendering)
│   └── test_config.py       # ConfigManager tests
└── src/pi0disp/
    ├── __init__.py           # Exports: ST7789V, ConfigManager, TextTicker
    ├── __main__.py           # CLI entry point (click)
    ├── core/                 # Core driver modules
    │   ├── driver.py         # ST7789V driver (Actuator ABC)
    │   └── renderer.py       # ColorConverter (numpy LUT), RegionOptimizer
    ├── config/               # Configuration management
    │   └── config_manager.py # display.json CRUD + interactive wizard
    ├── effects/              # Visual effects
    │   └── text_ticker.py    # Scrolling marquee animation
    ├── fonts/                # Bundled multilingual fonts
    │   ├── NotoSans-Regular.ttf      # English
    │   ├── NotoSansJP-Regular.otf    # Japanese
    │   └── NotoSansTC-Regular.otf    # Traditional Chinese
    └── cli/                  # CLI subcommands
        ├── init_cmd.py       # First-time setup wizard
        ├── image_cmd.py      # Display image file
        ├── text_cmd.py       # Static/scrolling text
        ├── demo_cmd.py       # Bouncing ball animation
        ├── info_cmd.py       # Driver state + health check
        └── display_tool.py   # Interactive menu tool
```

---

## Installation (Raspberry Pi)

### Prerequisites

- **Raspberry Pi Zero 2W** (or compatible)
- **pigpiod** daemon running (`sudo pigpiod`)
- **SPI enabled** (`sudo raspi-config` → Interface Options → SPI)
- **uv** package manager

### Install

```bash
cd ~/NinjaRobotPi0

# Method A: Install with all project packages (recommended)
uv sync

# Method B: Install pi0disp standalone
uv pip install -e ./pi0disp
```

> [!IMPORTANT]
> **pigpiod daemon required**: `pigpio` (the Python library) is installed automatically,
> but the **system daemon** must be running before using pi0disp:
> ```bash
> sudo pigpiod          # Start the daemon
> pigs t                # Verify it's running (should print a timestamp)
> ```
> To start pigpiod automatically on boot:
> ```bash
> sudo systemctl enable pigpiod
> ```

### First-Time Setup

Run the interactive configuration wizard to set your GPIO pin assignments:

```bash
uv run pi0disp init
```

The wizard will guide you through:
1. **Display profile selection** (ST7789V 2.8" or Waveshare 2.0")
2. **DC pin** (default: GPIO 14)
3. **RST pin** (default: GPIO 15)
4. **Backlight pin** (default: GPIO 16)
5. **Rotation** (0°, 90°, 180°, 270°)
6. **Brightness** (0-100%)

This creates a `display.json` configuration file.

For non-interactive setup with defaults:
```bash
uv run pi0disp init --defaults
```

---

## CLI Commands

**Entry Point:** `uv run pi0disp <command>`

### Setup & Configuration

| Command | Description |
|---|---|
| `pi0disp init` | Interactive display setup wizard |
| `pi0disp init --defaults` | Non-interactive setup with defaults |
| `pi0disp config show` | Show current configuration |
| `pi0disp config set <key> <value>` | Set a configuration value |
| `pi0disp config export <path>` | Export config to a file |
| `pi0disp config import <path>` | Import config from a file |
| `pi0disp info` | Show driver state, config, and health check |
| `pi0disp info --health-check` | Include hardware connectivity test |

### Display Operations

| Command | Description |
|---|---|
| `pi0disp image <path>` | Display an image (auto-resized to fit) |
| `pi0disp text "Hello"` | Display static text |
| `pi0disp text "Hello" --scroll` | Scrolling marquee text |
| `pi0disp text "こんにちは" --lang ja` | Japanese text with Noto font |
| `pi0disp text "你好" --lang zh-tw` | Traditional Chinese text |
| `pi0disp demo` | Bouncing ball animation demo |
| `pi0disp demo --num-balls 5` | Demo with 5 balls |
| `pi0disp clear` | Clear display (fill black) |
| `pi0disp brightness <0-100>` | Set backlight brightness |
| `pi0disp display-tool` | Interactive menu (9 options) |

### Command Examples

```bash
# First-time setup
uv run pi0disp init

# Display an image file
uv run pi0disp image ~/photos/robot_face.png

# Show scrolling Japanese text
uv run pi0disp text "忍者ロボットへようこそ！" --lang ja --scroll --speed 3

# Run bouncing ball demo (3 balls, 10 seconds)
uv run pi0disp demo --num-balls 3 --duration 10

# Adjust brightness to 50%
uv run pi0disp brightness 50

# Check configuration and health
uv run pi0disp info --health-check

# Export config for backup
uv run pi0disp config export ~/display_backup.json

# Launch interactive menu
uv run pi0disp display-tool
```

---

## Python API

### ST7789V Driver

The main display driver class. Implements `ninja_utils.Actuator` ABC.

**Module:** `pi0disp.core.driver`

```python
import pigpio
from PIL import Image
from pi0disp import ST7789V

# Create pigpio connection
pi = pigpio.pi()

# Initialize display (with defaults or custom pins)
lcd = ST7789V(
    pi=pi,
    channel=0,          # SPI channel (0 or 1)
    dc_pin=14,          # Data/Command GPIO
    rst_pin=15,         # Reset GPIO
    backlight_pin=16,   # Backlight GPIO
    speed_hz=32_000_000,# SPI clock speed
    width=240,          # Display width
    height=320,         # Display height
    rotation=0,         # 0, 90, 180, or 270
)

# Display an image (auto-resized, delta rendering)
img = Image.open("robot_face.png").convert("RGB")
lcd.display(img)

# Set brightness (0-100%)
lcd.set_brightness(80)

# Clear display
lcd.clear()
lcd.clear(color=(255, 0, 0))  # Fill with red

# Display a sub-region
lcd.display_region(img, x0=0, y0=0, x1=120, y1=160)

# Change rotation
lcd.set_rotation(90)

# Power management
lcd.sleep()    # Enter low-power mode
lcd.wake()     # Exit low-power mode

# Health check
is_ok = lcd.health_check()

# Cleanup
lcd.close()
pi.stop()
```

**Context Manager:**
```python
with ST7789V(pi=pi) as lcd:
    lcd.display(Image.open("face.png").convert("RGB"))
    lcd.set_brightness(50)
# Automatically closed on exit
```

#### ST7789V Method Reference

| Method | Returns | Description |
|---|---|---|
| `display(image)` | `None` | Display image with smart delta rendering (thread-safe) |
| `display_region(image, x0, y0, x1, y1)` | `None` | Display a sub-region (thread-safe) |
| `clear(color=(0,0,0))` | `None` | Fill display with solid color |
| `set_brightness(percent)` | `None` | Set backlight PWM (0-100%) |
| `set_rotation(degrees)` | `None` | Set rotation (0, 90, 180, 270) |
| `sleep()` | `None` | Enter low-power sleep mode |
| `wake()` | `None` | Wake from sleep mode |
| `health_check()` | `bool` | Verify SPI connection is alive |
| `close()` | `None` | Release SPI handle, GPIO, and backlight |
| `initialize()` | `None` | Actuator ABC: wake display |
| `execute(command)` | `None` | Actuator ABC: dispatch command dict |
| `off()` | `None` | Actuator ABC: sleep + backlight off |

#### Actuator ABC Interface

For `ninja_core` HAL integration, the driver implements the `Actuator` ABC:

```python
# Via ninja_core HAL (e.g., from web_server.py or dispatcher.py)
lcd.execute({"image": my_pil_image})     # Display an image
lcd.execute({"brightness": 50})           # Set brightness
lcd.execute({"backlight": 80})            # Alias for brightness
lcd.execute({"clear": True})              # Clear display
lcd.execute({"rotation": 90})             # Set rotation
```

---

### ConfigManager

Manages display settings via a project-relative `display.json` file.

**Module:** `pi0disp.config.config_manager`

```python
from pi0disp import ConfigManager

cm = ConfigManager()            # Uses default display.json path
cfg = cm.load()                  # Load (or create defaults)
print(cfg["dc_pin"])             # → 14

cm.set("brightness", 80)        # Update a value
cm.save()                        # Persist to disk

cm.export_config("backup.json")  # Export to file
cm.import_config("backup.json")  # Import from file
```

#### ConfigManager Method Reference

| Method | Returns | Description |
|---|---|---|
| `load()` | `dict` | Load config from `display.json` (defaults if missing) |
| `save()` | `None` | Save current config to disk |
| `get(key, default)` | `Any` | Get a config value |
| `set(key, value)` | `None` | Set a value and save |
| `export_config(path)` | `None` | Export config to a file |
| `import_config(path)` | `dict` | Import config from a file |
| `init_config(interactive)` | `dict` | Interactive or default setup wizard |
| `config_path` | `str` | Property: path to `display.json` |

#### Default Configuration

```json
{
    "display_profile": "ST7789V 2.8-inch IPS TFT",
    "dc_pin": 14,
    "rst_pin": 15,
    "backlight_pin": 16,
    "width": 240,
    "height": 320,
    "rotation": 0,
    "brightness": 100,
    "spi_speed_mhz": 32
}
```

---

### TextTicker

Scrolling marquee text animation with multilingual font support.

**Module:** `pi0disp.effects.text_ticker`

```python
from pi0disp import ST7789V
from pi0disp.effects.text_ticker import TextTicker
import time

lcd = ST7789V(pi=pi)

# Create a ticker with Japanese text
ticker = TextTicker(
    lcd=lcd,
    text="忍者ロボットへようこそ！",
    font_size=32,
    color=(0, 255, 128),      # Green text
    bg_color=(0, 0, 0),       # Black background
    speed=2.0,                 # Pixels per frame
    language="ja",             # Use NotoSansJP font
)

# Start scrolling (runs in background thread)
ticker.start()

time.sleep(10)  # Let it scroll for 10 seconds

# Stop and cleanup
ticker.stop()
lcd.close()
```

#### TextTicker Method Reference

| Method | Returns | Description |
|---|---|---|
| `start()` | `None` | Start scrolling in a background thread (daemon) |
| `stop()` | `None` | Stop the animation and join the thread |
| `is_running()` | `bool` | Check if the ticker is currently animating |

#### Supported Languages

| Code | Font | Example |
|---|---|---|
| `en` | NotoSans-Regular.ttf | Hello World |
| `ja` | NotoSansJP-Regular.otf | こんにちは |
| `zh-tw` | NotoSansTC-Regular.otf | 你好世界 |

---

### Renderer Utilities

Internal utilities for optimized display rendering.

**Module:** `pi0disp.core.renderer`

#### ColorConverter

Fast RGB → RGB565 color conversion using numpy lookup tables (LUT).

```python
from pi0disp.core.renderer import ColorConverter
import numpy as np

cc = ColorConverter()

# Convert an RGB image array to RGB565 bytes
rgb_array = np.array(image)  # shape: (height, width, 3)
pixel_bytes = cc.rgb_to_rgb565_bytes(rgb_array)
```

#### RegionOptimizer

Optimizes rectangular dirty regions for partial display updates.

```python
from pi0disp.core.renderer import RegionOptimizer

# Clamp a region to display boundaries
clamped = RegionOptimizer.clamp_region((−10, −5, 250, 350), width=240, height=320)
# → (0, 0, 240, 320)

# Merge overlapping/nearby regions to reduce SPI transfers
regions = [(0, 0, 50, 50), (45, 0, 100, 50), (200, 200, 240, 240)]
merged = RegionOptimizer.merge_regions(regions, max_regions=2)
```

---

## Raspberry Pi Testing Guide

Follow these steps to validate pi0disp on your Raspberry Pi:

### Step 1: Verify Prerequisites

```bash
# Ensure SPI is enabled
ls /dev/spidev0.0
# → Should show the device file

# Ensure pigpiod is running
pigs t
# → Should return a timestamp number

# Ensure pi0disp is installed
uv run pi0disp --help
# → Should show the list of commands
```

### Step 2: Initial Setup

```bash
uv run pi0disp init
```

Follow the prompts to select your display profile and configure GPIO pins.

### Step 3: Test Display

```bash
# Clear the screen (should turn off any previous content)
uv run pi0disp clear

# Display a test image
uv run pi0disp image assets/images/sample_face.jpg
```

You should see the image rendered on the display.

### Step 4: Test Brightness

```bash
# Set to 50%
uv run pi0disp brightness 50

# Set to 100% (full brightness)
uv run pi0disp brightness 100

# Set to 0% (backlight off)
uv run pi0disp brightness 0
```

### Step 5: Test Text Rendering

```bash
# Static English text
uv run pi0disp text "Hello NinjaRobot"

# Scrolling Japanese text
uv run pi0disp text "忍者ロボットへようこそ！" --lang ja --scroll

# Scrolling Chinese text
uv run pi0disp text "你好世界" --lang zh-tw --scroll --speed 3
```

### Step 6: Test Animation

```bash
# Run bouncing ball demo
uv run pi0disp demo --num-balls 3

# Press Ctrl+C to stop
```

### Step 7: Check Health & Configuration

```bash
# View current configuration
uv run pi0disp info --health-check

# Or check config only
uv run pi0disp config show
```

### Step 8: Test Interactive Menu

```bash
uv run pi0disp display-tool
```

Choose from 9 options to exercise all functionality interactively.

### Troubleshooting

| Symptom | Cause | Solution |
|---|---|---|
| `Error: pigpio not available` | Not on Raspberry Pi or pigpiod not running | Run `sudo pigpiod` |
| `Error: Could not connect to pigpio daemon` | pigpiod crashed or not started | `sudo systemctl restart pigpiod` |
| Display shows nothing | Wrong SPI or GPIO pin config | Re-run `uv run pi0disp init` |
| Display garbled/inverted | Wrong rotation setting | `uv run pi0disp config set rotation 0` |
| `ModuleNotFoundError: pi0disp` | Package not installed | `cd ~/NinjaRobotPi0 && uv sync` |
| White screen / no backlight | Backlight pin wrong | Check wiring, re-run `uv run pi0disp init` |

---

## Development (PC/Mac)

No hardware is required for development — all hardware calls are mocked in tests.

```bash
cd pi0disp

# Install dev dependencies
uv sync --group dev

# Run unit tests (54 tests, ~27 seconds)
uv run pytest tests/ -v

# Lint
uv run ruff check src/ tests/

# Auto-fix lint errors
uv run ruff check src/ tests/ --fix
```

### Test Coverage

| Suite | Tests | Coverage |
|---|---|---|
| `test_renderer.py` | 12 | ColorConverter (RGB565 accuracy for R/G/B/W/K), RegionOptimizer (clamp, merge, max_regions) |
| `test_driver.py` | 22 | Construction, delta rendering, brightness, rotation, Actuator ABC, power management, thread safety, context manager |
| `test_config.py` | 10 | Load/save, get/set, export/import, init_config, corrupted JSON, display profiles |
| **Total** | **54** | |

---

## Architecture

```
┌─────────────────────────────────────────────────┐
│                  CLI (__main__.py)               │
│  init │ image │ text │ demo │ info │ display-tool│
├───────────────────┬─────────────────────────────┤
│   ConfigManager   │       TextTicker            │
│ (config_manager)  │   (text_ticker.py)          │
├───────────────────┴─────────────────────────────┤
│               ST7789V Driver (driver.py)        │
│        Actuator ABC │ Thread-safe SPI Lock      │
│        Delta Render │ PWM Brightness            │
├─────────────────────────────────────────────────┤
│           Renderer (renderer.py)                │
│     ColorConverter (numpy LUT) │ RegionOptimizer│
├─────────────────────────────────────────────────┤
│            pigpio (SPI / GPIO / PWM)            │
└─────────────────────────────────────────────────┘
```

## License

MIT License — © 2026 Chihkuang Chang

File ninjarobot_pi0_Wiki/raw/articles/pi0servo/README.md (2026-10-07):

# pi0servo

**Velocity-based servo control library for Raspberry Pi Zero / Raspberry Pi**

A lightweight, physics-based servo control library designed for SG90/MG90S micro servos. Features smooth easing curves, per-servo speed limits, and an interactive calibration tool.

## ✨ Key Features

- **Velocity-based Motion** – Physics calculations (degrees/sec) instead of arbitrary durations
- **100Hz Update Rate** – 10ms step interval for smooth, jitter-free motion
- **Cubic Easing (Default)** – Uses `ease_in_out_cubic` for natural S-curve acceleration
- **Per-Servo Speed Limits** – Individual speed limits (0-100%) prevent mechanical stress
- **Thread-safe Abort** – Immediately stop any running movement
- **Interactive Tools** – Menu-driven `servo-tool` for calibration and testing

## 📋 Requirements

- Raspberry Pi (Zero, Zero 2W, 3, 4, or 5)
- Python 3.9 or higher
- `pigpio` daemon running
- SG90 or MG90S servo motors

---

## 🚀 Installation

### Step 1: Install System Dependencies

```bash
# Install pigpio (GPIO daemon for precise PWM control)
sudo apt update
sudo apt install -y pigpio python3-pigpio

# Enable and start the pigpio daemon
sudo systemctl enable pigpiod
sudo systemctl start pigpiod
```

### Step 2: Clone the Repository

```bash
git clone https://github.com/your-repo/pi0servo.git
cd pi0servo
```

### Step 3: Install with uv (Recommended)

```bash
# Install uv if not already installed
curl -LsSf https://astral.sh/uv/install.sh | sh

# Install all dependencies (automatically creates .venv/)
uv sync
```

> [!NOTE]
> `uv sync` automatically creates and manages the virtual environment. You don't need to manually run `uv venv` or `source .venv/bin/activate`.

### Alternative: Install with pip

```bash
# Create virtual environment
uv venv
source .venv/bin/activate

# Install dependencies
uv pip install pigpio click blessed

# Install pi0servo
uv pip install -e .
```

### Step 4: Verify Installation

```bash
# Check pigpio daemon is running
pigs t  # Should return 0 or small number

# Test pi0servo CLI
uv run pi0servo --help
```

---

## 🎮 Quick Start

> [!CAUTION]
> **Calibration is REQUIRED before use.** Uncalibrated servos will not move. This is a safety feature to prevent unexpected servo damage.

### 1. Start the Interactive Tool

```bash
sudo pigpiod                    # Ensure daemon is running
uv run pi0servo servo-tool
```

### 2. Main Menu

```
╔══════════════════════════════════════════════════════════╗
║           pi0servo Interactive Tool                      ║
╠══════════════════════════════════════════════════════════╣
║  1. Quick Move    - Enter commands like '17:30/27:M'     ║
║  2. Single Move   - Move one servo to angle              ║
║  3. Calibrate     - Launch calibration TUI               ║
║  4. Set Speed     - Adjust servo speed limit             ║
║  5. Status        - Show all servo configs               ║
║  6. Config        - Show/export/import config            ║
║  q. Exit                                                 ║
╚══════════════════════════════════════════════════════════╝
```

### 3. First-Time Setup: Calibrate Your Servos

> [!IMPORTANT]
> **Calibration is required before use.** Each servo has unique pulse width characteristics.

1. Select option **3. Calibrate**
2. Enter the GPIO pin number your servo is connected to
3. Use the calibration TUI to find the correct pulse widths:

| Key | Action |
|-----|---|
| **Tab / Shift+Tab** | Cycle through Min, Center, Max |
| **Up / Down** | Large pulse adjustment (±20μs) |
| **w / s** | Fine adjustment (±1μs) |
| **+ / -** | Adjust speed limit |
| **Enter** | Save calibration |
| **q** | Quit |

---

### 📋 Command Format

Commands use the **movement-tool** format:

```
[GLOBAL_SPEED_]PIN:ANGLE[LOCAL_SPEED][/PIN:ANGLE[LOCAL_SPEED]...]
```

### Examples

| Command | Description |
|---|---|
| `20:45` | Move GPIO20 to 45° at medium speed (default) |
| `F_20:45` | Move GPIO20 to 45° at **Fast** speed (global) |
| `M_20:45/21:-30` | Move two servos at **Medium** speed |
| `S_20:C/21:MF` | Move 20 to Center (Slow), 21 to Min (**Fast override**) |
| `20:45S` | Move GPIO20 to 45° at **Slow** speed |

### Speed Modes

| Prefix | Mode | Description |
|---|---|---|
| `F_` | Fast | Maximum velocity |
| `M_` | Medium | Default balanced speed |
| `S_` | Slow | Gentle movement |

### Special Angles

| Symbol | Meaning |
|---|---|
| `C` | Center (0°) |
| `M` | Min (-90°) |
| `X` | Max (90°) |

---

## 🔧 CLI Commands

```bash
# Interactive tool (recommended)
uv run pi0servo servo-tool

# Calibration
uv run pi0servo calib 20          # Calibrate pin 20
uv run pi0servo calib --show      # Show all calibrations

# Single servo
uv run pi0servo move 20 45        # Move to 45°
uv run pi0servo move 20 center    # Move to center

# Multi-servo command
uv run pi0servo cmd "F_20:45/21:-30"

# Configuration
uv run pi0servo config show
uv run pi0servo config export backup.json
uv run pi0servo config import backup.json
```

---

## 🐍 Python API

### Basic Usage

```python
import pigpio
from pi0servo import ServoGroup, ConfigManager

pi = pigpio.pi()

# Load calibrations
manager = ConfigManager()
manager.load()
calibrations = {20: manager.get_calibration(20)}

# Create servo group
group = ServoGroup(pi, pins=[20], calibrations=calibrations)

# Move servo
group.move_all_sync(targets=[45], speed_mode="M")

# Cleanup
group.off()
pi.stop()
```

### Async Usage

```python
await group.move_all_async(targets=[45], speed_mode="M")

# Abort from another thread
group.abort()
```

---

## 📁 Configuration File

Calibration is stored in `servo.json`:

```json
{
  "20": {
    "pulse_min": 500,
    "pulse_center": 1500,
    "pulse_max": 2500,
    "speed": 80
  }
}
```

> [!NOTE]
> **Default (uncalibrated) values are all `1500`** (center position). This means an uncalibrated servo will not move - you MUST calibrate each servo first.

---

## 🌊 Easing Functions

| Easing | Behavior |
|---|---|
| `ease_in_out_cubic` | Smooth S-curve at both ends **(DEFAULT)** |
| `ease_out_cubic` | Fast start, very slow finish |
| `ease_in_cubic` | Very slow start, fast finish |
| `ease_in_out` | Quadratic S-curve (less smooth) |
| `ease_out` | Fast start, slow finish |
| `ease_in` | Slow start, fast finish |
| `linear` | Constant speed |

> [!TIP]
> Cubic easing provides smoother motion than quadratic. The default `ease_in_out_cubic` combined with 100Hz update rate minimizes visible jitter.

---

## 🔌 Hardware Wiring

Connect SG90 servos to GPIO pins:

| Servo Wire | Raspberry Pi |
|---|---|
| **Red** (VCC) | 5V Power |
| **Brown** (GND) | Ground |
| **Orange** (Signal) | GPIO pin (e.g., GPIO 20) |

> [!WARNING]
> Use external 5V power supply for multiple servos. Pi's 5V pin cannot safely power more than 1-2 servos.

---

## License

MIT License - See [LICENSE](LICENSE) for details.

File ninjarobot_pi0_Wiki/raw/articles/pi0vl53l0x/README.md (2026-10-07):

# pi0vl53l0x

A robust Python driver for the VL53L0X Time-of-Flight distance sensor using pigpio.

## Features

- **Hardened initialization** — firmware boot polling (up to 1.0s) prevents "returns 0 after reboot" issue
- **Thread-safe ranging** — individual I2C operations and whole single-shot ranging transactions are serialized for background monitor + Blockly use
- **Automatic retry** — exponential backoff (10→20→50ms) with bus recovery on persistent failure
- **Defined exception contract** — `I2CError`, `TimeoutError`, `RuntimeError` for clear error handling
- **Async ready** — `get_range_async()` for asyncio integration
- **Config management** — JSON-based offset storage with export/import
- **Interactive CLI** — `sensor-tool` TUI with 8 menu options for guided sensor operations
- **Individual commands** — `get`, `test`, `status`, `calibrate`, `performance`, `config` for scripting
- **100% backward compatible** — drop-in replacement for ninja_core integration

## Directory Structure

```
pi0vl53l0x/
├── pyproject.toml              # Package metadata, dependencies, CLI entry point
├── README.md                   # This document
├── LICENSE
├── tests/                      # Unit tests (61 tests total)
│   ├── test_i2c.py             # I2C bus wrapper tests (22 tests)
│   ├── test_sensor.py          # VL53L0X driver tests (23 tests)
│   └── test_config.py          # Config manager tests (16 tests)
└── src/pi0vl53l0x/
    ├── __init__.py              # Package exports (VL53L0X, ConfigManager, I2CError)
    ├── __main__.py              # Entry point for `python -m pi0vl53l0x`
    ├── registers.py             # ~60 semantic register constants
    ├── driver.py                # Backward-compat shim (re-exports VL53L0X from core)
    ├── core/                    # Core sensor modules
    │   ├── __init__.py
    │   ├── i2c.py               # Thread-safe I2C bus wrapper with retry + recovery
    │   └── sensor.py            # VL53L0X driver (~1000 lines, implements Sensor ABC)
    ├── config/                  # Configuration management
    │   ├── __init__.py
    │   └── config_manager.py    # JSON load/save/export/import
    └── cli/                     # CLI commands
        ├── __init__.py
        └── sensor_tool.py       # Individual commands + interactive sensor-tool TUI
```

## Requirements

- Python ≥ 3.9
- `click` — CLI framework
- `blessed` — Terminal UI for interactive tool
- `ninja_utils` — logging and Sensor ABC
- `pigpio` — Raspberry Pi I2C (required on RPi)

## Installation (Standalone on Raspberry Pi)

### Step 1: Install `uv` (Python package manager)

```bash
curl -LsSf https://astral.sh/uv/install.sh | sh
source ~/.bashrc    # or restart your terminal
```

> **Note:** `uv` is a fast Python package manager that replaces `pip` and `venv`. It automatically creates a `.venv` and manages all dependencies.

### Step 2: Clone and install pi0vl53l0x

```bash
# Clone the repository (or copy the pi0vl53l0x folder to your Pi)
cd pi0vl53l0x

# Install all dependencies including pigpio for Raspberry Pi
uv sync --extra pi
```

### Step 3: Start pigpiod

```bash
sudo pigpiod
```

> **Tip:** To start pigpiod automatically on boot:
> ```bash
> sudo systemctl enable pigpiod
> ```

### Step 4: Verify installation

```bash
uv run pi0vl53l0x --help
uv run pi0vl53l0x test
```

## CLI — Interactive Sensor Tool

Launch the interactive TUI with 8 menu options for guided sensor operations:

```bash
# Launch the interactive TUI
uv run pi0vl53l0x sensor-tool

# With custom config file
uv run pi0vl53l0x sensor-tool --config my_sensor.json
```

The `sensor-tool` provides a menu-driven interface:

| # | Function | Description |
|---|---|---|
| 1 | Single Read | Take one distance measurement (repeat with Enter) |
| 2 | Continuous Read | Stream readings at configurable interval |
| 3 | Performance | Measure readings/second with statistics |
| 4 | Calibrate | Guided offset calibration at known distance |
| 5 | Health Check | Verify sensor connection and test reading |
| 6 | Status | Full diagnostics (health, offset, config, reading) |
| 7 | Config | Show/export/import sensor settings |
| 8 | Reinitialize | Reset sensor for recovery from stuck state |

## CLI — Individual Commands

Individual commands are ideal for scripting, automation, and quick one-off operations.

### Read Distance

```bash
# Single reading
uv run pi0vl53l0x get

# 10 readings at 0.5s intervals
uv run pi0vl53l0x get --count 10 --interval 0.5
```

### Quick Test

```bash
# Initialize sensor and take 5 test readings
uv run pi0vl53l0x test
```

### Health Status

```bash
# Full sensor health report (connection, offset, reading, config)
uv run pi0vl53l0x status
```

### Performance Benchmark

```bash
# Measure readings per second (100 samples)
uv run pi0vl53l0x performance --count 100
```

### Calibration

```bash
# Place a target at exactly 100mm from sensor, then run:
uv run pi0vl53l0x calibrate --distance 100 --count 10
```

### Configuration Management

```bash
# View current settings
uv run pi0vl53l0x config show

# Backup configuration
uv run pi0vl53l0x config export backup.json

# Restore configuration
uv run pi0vl53l0x config import backup.json
```

### Global Options

```bash
# Enable debug logging
uv run pi0vl53l0x --debug get --count 5

# Use custom config file
uv run pi0vl53l0x --config-file custom.json get
```

## Quick Start

### Python API

```python
import pigpio
from pi0vl53l0x import VL53L0X

pi = pigpio.pi()
sensor = VL53L0X(pi)  # Auto-initializes with firmware boot polling

# Single measurement
distance = sensor.get_range()
print(f"Distance: {distance} mm")

# Structured data with validity check
data = sensor.get_data()
if data["is_valid"]:
    print(f"Distance: {data['distance_mm']} mm (raw: {data['raw_value']} mm)")

# Calibration at known distance
offset = sensor.calibrate(target_distance_mm=100, num_samples=10)
sensor.set_offset(offset)

# Health check and recovery
if not sensor.health_check():
    sensor.reinitialize()

sensor.close()
pi.stop()
```

### Context Manager

```python
with VL53L0X(pi) as sensor:
    distance = sensor.get_range()
```

### Async Support

```python
distance = await sensor.get_range_async()
```

### Using with ninja_core (HAL Integration)

The library is loaded automatically by `ninja_core/hal.py` via the driver registry:

```python
# ninja_core imports it as:
from pi0vl53l0x.driver import VL53L0X
sensor = VL53L0X(pi)  # driver.py is a shim that re-exports from core.sensor
```

No changes to `ninja_core` are needed — both import paths work identically.

## API Reference

### VL53L0X (Constructor)

```python
VL53L0X(
    pi: pigpio.pi,
    i2c_bus: int = 1,
    i2c_address: int = 0x29,
    debug: bool = False,
    config_file_path: str | None = None,
    firmware_boot_timeout: float = 1.0,
)
```

| Parameter | Default | Description |
|---|---|---|
| `pi` | (required) | Shared pigpio connection |
| `i2c_bus` | `1` | I2C bus number |
| `i2c_address` | `0x29` | 7-bit I2C address |
| `debug` | `False` | Enable debug logging |
| `config_file_path` | `None` | Path to JSON config with `offset_mm` |
| `firmware_boot_timeout` | `1.0` | Firmware boot timeout in seconds |

> **Note:** The constructor auto-calls `initialize()`. If init fails, the I2C handle is cleaned up automatically.

### Measurement Methods

| Method | Returns | Description |
|---|---|---|
| `get_range()` | `int` | Single-shot distance in mm (with offset applied) |
| `get_data()` | `dict` | `{"distance_mm", "is_valid", "raw_value", "timestamp"}` |
| `get_ranges(num_samples)` | `list[int]` | Multiple consecutive measurements |
| `get_range_async()` | `int` | Async version (runs in thread pool executor) |

### Thread Safety

`I2CBus` serializes individual register reads and writes. `VL53L0X` also serializes the complete single-shot ranging transaction with an internal re-entrant measurement lock, so a background `DistanceMonitor` read and Blockly user code calling `robot.distance.read()` cannot interleave the register writes that start, poll, and clear a measurement.

`get_range()`, `get_data()`, `get_ranges()`, `get_range_async()`, `reinitialize()`, and `close()` all use this transaction-level protection where needed. This is important inside NinjaRobotPi0 because the web IDE can execute Blockly loops while the server is also polling the same physical VL53L0X sensor.

### Calibration & Configuration

| Method | Returns | Description |
|---|---|---|
| `set_offset(offset_mm)` | `None` | Set distance offset in mm |
| `calibrate(target_distance_mm, num_samples)` | `int` | Measure and return calculated offset |

### Health & Recovery

| Method | Returns | Description |
|---|---|---|
| `health_check()` | `bool` | Verify sensor responds (reads Model ID) |
| `reinitialize()` | `None` | Full re-init for recovery; serialized with active ranging transactions |
| `close()` | `None` | Release I2C handle |

### I2CBus

Thread-safe I2C wrapper used internally by VL53L0X. It protects individual bus operations; the VL53L0X driver layers a measurement transaction lock above it for multi-register ranging flows.

```python
from pi0vl53l0x.core.i2c import I2CBus

bus = I2CBus(pi, bus=1, address=0x29, max_retries=3)
value = bus.read_byte(0xC0)  # Read Model ID register
bus.close()
```

| Method | Returns | Description |
|---|---|---|
| `read_byte(register)` | `int` | Read single byte |
| `write_byte(register, value)` | `None` | Write single byte |
| `read_word_big_endian(register)` | `int` | Read 16-bit word (byte-swap) |
| `write_word_big_endian(register, value)` | `None` | Write 16-bit word (byte-swap) |
| `read_block(register, count)` | `list[int]` | Read block of bytes |
| `write_block(register, data)` | `None` | Write block of bytes |
| `close()` | `None` | Close I2C handle |

### ConfigManager

```python
from pi0vl53l0x.config import ConfigManager

manager = ConfigManager()         # Uses default vl53l0x.json path
manager.load()                    # Load config from file
manager.set("offset_mm", 10)      # Set a value
manager.save()                    # Save to file
manager.export_config("backup.json")
manager.import_config("backup.json")
```

### Exception Contract

| Exception | When |
|---|---|
| `I2CError` | I2C bus failure after all retries exhausted |
| `TimeoutError` | Measurement/firmware boot did not complete within timeout |
| `RuntimeError` | Sensor not initialized |
| `ConnectionError` | Invalid Model ID (expected 0xEE) or connection failure |

## Testing

```bash
# Run all unit tests (61 tests)
uv run --extra dev pytest tests/ -v

# Lint check
uv run --extra dev ruff check src/ tests/
```

### Test Coverage

| Test File | Tests | Coverage |
|---|---|---|
| `test_i2c.py` | 22 | I2C ops, retry, recovery, thread safety |
| `test_sensor.py` | 23 | Init, ranging, offset, health, async, transaction lock, compat |
| `test_config.py` | 16 | Load/save, export/import, corrupt JSON |

### Manual Testing on Raspberry Pi

1. Start pigpiod: `sudo pigpiod`
2. Quick test: `uv run pi0vl53l0x test`
3. Health check: `uv run pi0vl53l0x status`
4. Read distances: `uv run pi0vl53l0x get --count 5`
5. Calibrate: `uv run pi0vl53l0x calibrate --distance 100 --count 10`
6. Interactive tool: `uv run pi0vl53l0x sensor-tool`

## Architecture

```
┌──────────────────────────────────────────────┐
│                  ninja_core                   │
│     hal.py → from pi0vl53l0x.driver import   │
│              VL53L0X (backward-compat shim)   │
└─────────────────────┬────────────────────────┘
                      │
┌─────────────────────▼────────────────────────┐
│              pi0vl53l0x package                │
│                                               │
│  ┌──────────┐  ┌──────────┐  ┌────────────┐  │
│  │ core/    │  │ config/  │  │ cli/       │  │
│  │  i2c.py  │  │ config_  │  │ sensor_    │  │
│  │  sensor  │  │ manager  │  │ tool.py    │  │
│  │  .py     │  │ .py      │  │            │  │
│  └────┬─────┘  └────┬─────┘  └────┬───────┘  │
│       │              │              │          │
│  registers.py   vl53l0x.json    click CLI     │
└──────────────────────────────────────────────┘
                      │
              pigpio I2C (bus 1)
                      │
              VL53L0X sensor (0x29)
```

## License

MIT License — © 2026 Chihkuang Chang

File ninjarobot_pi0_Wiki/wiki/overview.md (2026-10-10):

---
type: Concept
title: NinjaRobotPi0 Platform Overview
description: Comprehensive overview of the NinjaRobotPi0 AI-powered educational and
  research robotics platform.
status: draft
generated:
  by: codex/migration-audit
  at: '2026-10-07T07:13:37.354382+00:00'
sources:
- id: src-20260822-readme
  resource: urn:llmwiki:source:src-20260822-readme
  title: NinjaRobotPi0 Readme
  content_hash: sha256:3f74856140111a6337bf8b83c58bef7be13f91df9742fc0e36be27ebd35b8df2
- id: src-20260822-developmentguide
  resource: urn:llmwiki:source:src-20260822-developmentguide
  title: NinjaRobotPi0 Development Guide
  content_hash: sha256:d1f8e19627223cb320b2e05df9a141c768ca0f418a7f77d160b6127d08c439e9
- id: src-20261007-2026-10-07-ninjarobot-pi0-repository-migration
  resource: urn:llmwiki:source:src-20261007-2026-10-07-ninjarobot-pi0-repository-migration
  title: 2026 10 07 Ninjarobot Pi0 Repository Migration
  content_hash: sha256:2651e2d6d359620e3f5f2b1080132a84c74321b4a018c92d672ffe9d420573aa
- id: src-20261007-2026-10-07-ninjarobot-pi0-migration-audit
  resource: urn:llmwiki:source:src-20261007-2026-10-07-ninjarobot-pi0-migration-audit
  title: 2026 10 07 Ninjarobot Pi0 Migration Audit
  content_hash: sha256:6c223e850e920baffe83a0fbcf3f7c4471a97f4fbcc823e93d5cd2e33666d4ab
- id: src-20261008-installationguide-3
  resource: urn:llmwiki:source:src-20261008-installationguide-3
  title: Installationguide
  content_hash: sha256:734051f87ce7f447ae50bee7863118612f55b5747cd42e3cb047662a5408081f
- id: src-20261008-developmentguide-3
  resource: urn:llmwiki:source:src-20261008-developmentguide-3
  title: Developmentguide
  content_hash: sha256:0fc10ebdf50056c8d26521e3251d265cf5b2a764c98b9b1c13f2204310385178
- id: src-20261007-2026-10-07-install-onboard-wiki-ui-2
  resource: urn:llmwiki:source:src-20261007-2026-10-07-install-onboard-wiki-ui-2
  title: Pi0 upgrade implementation and current UI contracts
  content_hash: sha256:1545ea683947c315a9ea0d4c30258c228e975a78e39062b2e045669fcff0cb9c
- id: src-20261007-2026-10-08-upgrade-audit
  resource: urn:llmwiki:source:src-20261007-2026-10-08-upgrade-audit
  title: Pi0 upgrade audit findings and boundaries
  content_hash: sha256:7112a6575c6288875e3fdad33679f094b22908e0ee729b29f5dfbfc55f48de64
- id: src-20261008-readme-5
  title: 'Pi0 four-language manual: audited content and rebased links'
  content_hash: sha256:7695f000c17ae1c1c206d9866184e934bd071867ecc218ebe087cd77442d4d73
  resource: urn:llmwiki:source:src-20261008-readme-5
- id: src-20261008-2026-10-08-trixie-support
  resource: urn:llmwiki:source:src-20261008-2026-10-08-trixie-support
  title: Trixie installer correction and validation boundary
  content_hash: sha256:3aae04cfab13e782c5748e8ca26721d860d0d842ac18c5544fd8ae0f82dc2945
- id: src-20261008-2026-10-08-installer-recovery
  resource: urn:llmwiki:source:src-20261008-2026-10-08-installer-recovery
  title: Installer diagnostics and recovery validation
  content_hash: sha256:416eea41c04d6dc6ed633fa695b276a48574d22eacb21db5131de3577dbe4fc3
- id: src-20261008-2026-10-08-installer-compatibility
  resource: urn:llmwiki:source:src-20261008-2026-10-08-installer-compatibility
  title: 2026 10 08 Installer Compatibility
  content_hash: sha256:7eaa21e7a1f79122e25e10dc37ae91a488aebe3ccff9db5e6c7b59db0684928f
- id: src-20261008-2026-10-08-readme-audit
  title: Pi0 README audit evidence and validation limits
  content_hash: sha256:7a945023f45ad2e179e5cae529665df9ed050bfe5cf36f440f857a02e28cfea4
  resource: urn:llmwiki:source:src-20261008-2026-10-08-readme-audit
- id: src-20261010-readme-4
  resource: urn:llmwiki:source:src-20261010-readme-4
  title: Readme
  content_hash: sha256:006bdb216531773f51628c304ea5ca9ffce7f7e65a3298d8fe0782e4cfe6129e
- id: src-20261010-modeladapterimplementation
  resource: urn:llmwiki:source:src-20261010-modeladapterimplementation
  title: Modeladapterimplementation
  content_hash: sha256:2c6480a2595936057adf1550e8860044d7269be1b6a860a1395d893ec7a78895
- id: src-20261010-modeladaptervalidation
  resource: urn:llmwiki:source:src-20261010-modeladaptervalidation
  title: Modeladaptervalidation
  content_hash: sha256:653ade7e3e622c23f29dad7eedb8417a1ed0da58869859db3eb08c7319905938
- id: src-20261010-readme-5
  resource: urn:llmwiki:source:src-20261010-readme-5
  title: Readme
  content_hash: sha256:bcd029ec39e6c98a1ef4c4df341b216b471009b7cc38836937efab7ee464a7f2
- id: src-20261010-developmentguide-4
  resource: urn:llmwiki:source:src-20261010-developmentguide-4
  title: Developmentguide
  content_hash: sha256:b82c27e23387051b0280adf428e34299bbfd65bcf2bcc80d3802027c4f3827bc
- id: src-20261010-shutdownvoicefixes
  resource: urn:llmwiki:source:src-20261010-shutdownvoicefixes
  title: Shutdownvoicefixes
  content_hash: sha256:bc56cba07d2aade0773ca839cb060aceb625af2a002344892a6e81f6c0b5c6fb
semantic_review:
  version: 1
  performed_by: agent:antigravity
  performed_at: '2026-10-10T17:27:33.106210+00:00'
  target_hash: sha256:72147d402f6324bebb8a2c32c1f3d373cbc53e1aba08771148183df19e621b94
  result: passed
  checks:
    source_support: passed
    contradictions: passed
    limitations: passed
    claim_strength: passed
    visual_evidence: not_applicable
  notes:
  - Reviewed platform overview against 2026-10-11 README snapshot, DevelopmentGuide.md,
    and ShutdownVoiceFixes.md.
  - Coordinated shutdown and browser speech typing verified in code; live robot and
    account validation remain pending.
---

# NinjaRobotPi0 Platform Overview

## Current setup and documentation

The installer targets Zero 2 W with Debian-based Raspberry Pi OS 64-bit; current requirements are below. `./install.sh` installs software; `./onboard.sh` guides existing hardware tools and Gemini/ngrok settings. Full current manuals are immutable versions inside `ninjarobot_pi0_Wiki`; root manuals preserve public links. Pi0 uses a Pi5-style navy/cyan web presentation with its existing control contracts. Real-device final validation remains pending. Current React metadata is 19.2.0; descriptions of React 18 in earlier reference material are historical. See [guided onboarding](concepts/guided-onboarding.md), [development workflow](concepts/development-workflow.md), [web design](concepts/web-interface-design.md), [installation manual](references/installation-guide.md), and [development manual](references/development-guide.md).[^src-20261008-installationguide-3] [^src-20261010-developmentguide-4]

**NinjaRobotPi0** is an advanced, modular AI robot platform designed for research and STEAM education, powered by the Raspberry Pi Zero 2W.[^src-20260822-readme] It integrates a multi-provider AI agent (Google Gemini, OpenAI, Anthropic Claude, and Ollama Cloud) with a mobile-first web interface, dual connectivity (Wi-Fi and Bluetooth Low Energy), and rebuilt non-blocking hardware drivers.[^src-20260822-readme] [^src-20260822-developmentguide] [^src-20261010-readme-4] [^src-20261010-modeladapterimplementation]

## Hardware Specifications

| Component | Specification | Details |
|---|---|---|
| **Brain / SBC** | Raspberry Pi Zero 2W | Quad-core ARM Cortex-A53 @ 1.0 GHz, 512MB RAM [^src-20260822-readme] |
| **Display** | 2.0" / 2.8" ST7789V IPS LCD | 240×320 pixels, SPI interface, PWM brightness control [^src-20260822-readme] [^src-20260822-developmentguide] |
| **Distance Sensor** | VL53L0X Time-of-Flight | Up to 2m documented range, I2C interface, distance readings in millimetres [^src-20260822-readme] |
| **Sound / Audio** | Passive Buzzer | GPIO 17, 35 musical notes (C3–B7), 14 emotion sounds [^src-20260822-readme] |
| **Actuators** | 8× SG90 / MG90S Servos | GPIO 20–27, velocity-based physics control [^src-20260822-readme] |
| **Connectivity** | Wi-Fi & Bluetooth | Wi-Fi 802.11n (2.4GHz), BLE 4.2 GATT Server [^src-20260822-readme] |

## Software Architecture

The NinjaRobot software stack is organized as a layered monorepo with 7 independent Python packages and a modern web application:[^src-20260822-developmentguide]

* **[Architecture & Hardware Abstraction Layer](concepts/architecture-and-hal.md)**: Dynamic driver registry and ABC interfaces in `ninja_utils`.[^src-20260822-developmentguide]
* **[Motion System & Easing](concepts/motion-system-and-easing.md)**: Velocity-based servo control and position-aware cubic easing curves.[^src-20260822-developmentguide]
* **[Dual Connectivity & Protocols](concepts/dual-connectivity-and-protocols.md)**: Centralized command dispatching across BLE and Web interfaces with chunked transport.[^src-20260822-developmentguide]
* **[Safe Execution & Blockly Runtime](concepts/safe-execution-and-blockly-runtime.md)**: Sandboxed code execution engine and dual runtime pipeline.[^src-20260822-developmentguide]
* **[Action Library & AI Agent](concepts/action-library-and-ai-agent.md)**: Multi-provider cloud model adapters (Google, OpenAI, Anthropic, Ollama Cloud), private credential storage, whole-plan action validation, and a persistent Blockly action library.[^src-20260822-readme] [^src-20260822-developmentguide] [^src-20261010-readme-4] [^src-20261010-modeladapterimplementation]
* **[Perception & Expression](concepts/perception-and-expression.md)**: Distance monitoring, animated facial expressions, and emotion audio queues.[^src-20260822-developmentguide]

## Component Packages

* **[NinjaRobotPi0 Entity](entities/ninjarobot-v5.md)**: High-level robot platform entity.[^src-20260822-readme]
* **[ninja_core](entities/ninja-core.md)**: Central application server, HAL, motion system, and web controllers.[^src-20260822-developmentguide]
* **[ninja_ble](entities/ninja-ble.md)**: BLE GATT server service supporting zero-network mobile connection.[^src-20260822-developmentguide]
* **[ninja_utils](entities/ninja-utils.md)**: Shared interfaces (`Sensor`, `Actuator`), logging, and system utilities.[^src-20260822-developmentguide]
* **[pi0servo](entities/pi0servo.md)**: Velocity-based multi-servo controller with easing.[^src-20260822-developmentguide]
* **[pi0disp](entities/pi0disp.md)**: Thread-safe ST7789V display driver with delta rendering.[^src-20260822-developmentguide]
* **[pi0buzzer](entities/pi0buzzer.md)**: Non-blocking passive buzzer driver with emotion sounds and melodies.[^src-20260822-developmentguide]
* **[pi0vl53l0x](entities/pi0vl53l0x.md)**: Hardened VL53L0X Time-of-Flight distance sensor driver.[^src-20260822-developmentguide]
* **[ninja_webapp](entities/ninja-webapp.md)**: React 18 + Vite frontend SPA with multilingual support.[^src-20260822-developmentguide]

## References & Deep Dives

* **[Installation & Wiring Guide](references/installation-and-wiring.md)**: Step-by-step assembly, wiring tables, and OS setup.[^src-20260822-developmentguide]
* **[Hardware Calibration & Tools](references/hardware-calibration-and-tools.md)**: Guided initialization and interactive TUIs for each subsystem.[^src-20260822-developmentguide]
* **[API & CLI Reference](references/api-and-cli-reference.md)**: Unified Python API, REST endpoints, and CLI commands.[^src-20260822-developmentguide]
* **[Driver Rebuild & Vulnerability Analysis](analyses/driver-rebuild-and-vulnerability-analysis.md)**: Evolution from legacy blocking drivers to non-blocking architectures.[^src-20260822-developmentguide]
* **[Development History & Evolution](analyses/development-history-and-evolution.md)**: Detailed chronology of V5 development phases and audits.[^src-20260822-developmentguide]

[^src-20260822-readme]: NinjaRobotPi0 Readme.
[^src-20260822-developmentguide]: NinjaRobotPi0 Development Guide.

## Repository migration (2026-10-07)

The former NinjaRobotV5 repository is now NinjaRobotPi0 at [NinjaRoboticsEducation/NinjaRobotPi0](https://github.com/NinjaRoboticsEducation/NinjaRobotPi0). The local folder is `NinjaRobotPi0/`. The new repository starts with fresh history on `main`; Python packages and robot runtime behavior are retained. Manual links use `blob/HEAD` to follow the GitHub default branch. Historical names and audit findings remain provenance; this migration does not resolve them.[^src-20261007-2026-10-07-ninjarobot-pi0-repository-migration]

[^src-20261007-2026-10-07-ninjarobot-pi0-repository-migration]: Registered evidence for the approved 2026-10-07 repository migration.

## Historical migration audit follow-up (2026-10-07)

Current repository documentation uses NinjaRobotPi0; historical audits and V5 version milestones retain their original identity. Robot runtime code and package names are unchanged. After a clean clone, prepare the embedded wiki with the normalization bootstrap in `NinjaRobotPi0/Wiki/NinjaRobotPi0_Wiki/README.md` before lint: its derived manifests are intentionally untracked. The tested bootstrap regenerates these through the existing CLI and restores zero-error normal lint. Website manuals use `blob/HEAD` and clone commands omit branch selection.[^src-20261007-2026-10-07-ninjarobot-pi0-migration-audit]

[^src-20261007-2026-10-07-ninjarobot-pi0-migration-audit]: Audit evidence covering documentation attribution, current naming, default-branch links, and clean-clone wiki normalization.

[^src-20261008-installationguide-3]: Current versioned Installationguide.

[^src-20261008-developmentguide-3]: Current versioned DevelopmentGuide.

## Implementation evidence and acceptance limits

Host validation and the exact code/tooling boundary are recorded in the approved implementation evidence. Real Pi hardware, live accounts and published curl acceptance remain pending; passing host checks do not imply physical acceptance.[^src-20261007-2026-10-07-install-onboard-wiki-ui-2]

[^src-20261007-2026-10-07-install-onboard-wiki-ui-2]: Pi0 upgrade implementation and current UI contracts.

## Historical 2026-10-08 audit follow-up (superseded policy)

The following records the earlier implementation; current compatibility policy below supersedes exact-version, codename and private-tool-precedence claims.

A comprehensive public README now follows Pi5 introduction, hardware/OS preparation, curl installation, guided initialization, browser access, first tests and troubleshooting. Japanese and Chinese sections are explicitly summaries. The wizard aligns its console flow with Pi5 while preserving Pi0 capabilities and manual runtime startup. See the current full manuals for the audit corrections and pending device acceptance.[^src-20261007-2026-10-08-upgrade-audit] [^src-20261008-developmentguide-3]

[^src-20261007-2026-10-08-upgrade-audit]: Pi0 upgrade audit findings and boundaries.

The public walkthrough is preserved as versioned README evidence.[^src-20261008-readme-5]

[^src-20261008-readme-5]: Pi0 public README — audit 2026-10-08.

## Historical Trixie support correction (superseded policy)

The following records the earlier implementation; current compatibility policy below supersedes exact-version, codename and private-tool-precedence claims.

The installer target now includes Bookworm (Debian 12) and Trixie (Debian 13), both 64-bit on Zero 2 W. The earlier rejection was the explicit Bookworm-only release check, not a failure of 64-bit detection. Both bootstrap and local/onboarding preflight have matching allowlists. Real Trixie hardware acceptance remains pending.[^src-20261008-2026-10-08-trixie-support]

[^src-20261008-2026-10-08-trixie-support]: Trixie installer correction and validation boundary.

## Historical Installation recovery and diagnostics (superseded policy)

The following records the earlier implementation; current compatibility policy below supersedes exact-version, codename and private-tool-precedence claims.

The current README provides explicit recovery steps: update Git by fetching default HEAD and fast-forwarding, run the installer, then check. Checks remain read-only and report versions, paths and retry commands. Installation failures identify their stage. This does not operate hardware or automatically update Git.[^src-20261008-2026-10-08-installer-recovery]

[^src-20261008-2026-10-08-installer-recovery]: Installer diagnostics and recovery validation.

## Current software compatibility policy

Installer checks now use compatibility instead of exact OS/Node/uv versions. No OS codename allowlist remains. The device, Linux aarch64, Debian-family OS, normal-user and Python 3.10+ requirements remain; optional wiki needs Python 3.11+. Bookworm/Trixie are reference targets, not a complete allowlist or proof of physical acceptance.[^src-20261008-2026-10-08-installer-compatibility]

[^src-20261008-2026-10-08-installer-compatibility]: Installer compatibility requirements and validation evidence.

## Multilingual user manual audit

The owner-expanded README has English, Japanese, Traditional Chinese and Simplified Chinese manuals. A documentation-only audit retained their structure and intentional omissions. It corrected service lifecycle, autostart uv discovery, ngrok behavior, hostname/shutdown assumptions and the unsupported core movement example. Necessary recovery/check details live in Troubleshooting/Appendix C. Robot implementation and dependencies are unchanged; physical acceptance remains separate.[^src-20261008-2026-10-08-readme-audit]

[^src-20261008-2026-10-08-readme-audit]: Four-language README correctness audit and code evidence.

## Cloud model provider adapters and private credentials (2026-10-10)

NinjaRobotPi0 expands AI chat beyond Google Gemini to include OpenAI, Anthropic (Claude), and Ollama Cloud through interactive CLI and onboarding selection (`ninja_core config select-model`, `init-tool` option 1, and `onboard.sh --step ai_model`).[^src-20261010-readme-4] [^src-20261010-modeladapterimplementation] Credentials are saved privately under `$XDG_CONFIG_HOME/ninjarobot_pi0/credentials/` (file mode `0600`, directory mode `0700`) with opaque references in `config.json`.[^src-20261010-modeladapterimplementation] Native voice input is gated by model capabilities (enabled for qualified Gemini models, disabled for OpenAI, Anthropic, and Ollama Cloud).[^src-20261010-modeladapterimplementation] [^src-20261010-modeladaptervalidation]

[^src-20261010-readme-4]: NinjaRobotPi0 Readme (2026-10-10 model adapter release).
[^src-20261010-modeladapterimplementation]: Pi0 Cloud Model Provider Adapter implementation evidence.
[^src-20261010-modeladaptervalidation]: Cloud model adapter validation report.

## Server shutdown and voice input corrections (2026-10-11)

Recent updates resolve server exit and browser microphone regressions:[^src-20261010-readme-5] [^src-20261010-shutdownvoicefixes]
* **Safe Server Exit**: Server shutdown coordinates an asynchronous cleanup sequence that executes the configured `Poweroff` rest posture before releasing GPIO and hardware handles, eliminating signal replay errors on Ctrl+C.[^src-20261010-shutdownvoicefixes]
* **Universal Browser Speech Typing**: Web Speech recognition transcribes voice into chat text across Google, OpenAI, Anthropic, and Ollama Cloud models independently of direct model audio processing capabilities.[^src-20261010-readme-5] [^src-20261010-shutdownvoicefixes]

[^src-20261010-readme-5]: NinjaRobotPi0 English README snapshot (2026-10-11 shutdown & voice fixes).
[^src-20261010-developmentguide-4]: Current versioned DevelopmentGuide (2026-10-11 shutdown & voice fixes).
[^src-20261010-shutdownvoicefixes]: Server shutdown and browser voice regression repair evidence note.

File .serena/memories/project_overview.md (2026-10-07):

# NinjaRobotPi0 - Project Overview

## Purpose
NinjaRobotPi0 is an AI-powered educational robot platform running on **Raspberry Pi Zero 2W**. It features **dual connectivity** (BLE + Web), a **Gemini AI agent** for natural language control, and a modular plugin architecture.

## Tech Stack
- **Language:** Python 3.11+
- **Async Framework:** asyncio (all I/O must be non-blocking)
- **Web Server:** FastAPI + Uvicorn + WebSocket
- **AI Agent:** Google Gemini via `google-genai` SDK
- **BLE:** `bless` (GATT server) + `bleak` (BLE backend) + `dbus-fast`
- **GPIO:** `pigpio` (daemon-based, precise PWM)
- **Display:** ST7789V via SPI (PIL/Pillow for rendering)
- **Package Manager:** `uv` (NOT pip)
- **Hardware:** Raspberry Pi Zero 2W, SG90 servos, ST7789V display, passive buzzer, VL53L0X ToF sensor

## Architecture

### Core Packages
| Package | Role |
|---|---|
| `ninja_core` | Orchestrator: HAL, Config, CommandDispatcher, AI Agent, Web Server, Movement, Faces, Sound, Perception |
| `ninja_ble` | BLE GATT server with chunking protocol |
| `ninja_utils` | Shared utilities: logging, interfaces (ABCs), systemd service management |
| `ninja_webapp` | Web frontend (served by FastAPI) |

### Hardware Driver Libraries (Plugins)
| Library | Purpose | ABC |
|---|---|-----|
| `pi0servo` | Velocity-based servo control (8ch), easing curves, interactive calibration | `Actuator` |
| `pi0disp` | ST7789V display rendering, face animations | `Actuator` |
| `pi0buzzer` | Non-blocking PWM sound, thread-safe queue | `Actuator` |
| `pi0vl53l0x` | VL53L0X ToF distance sensor, continuous monitoring | `Sensor` |

### Key Design Patterns
- **Hardware Abstraction Layer (HAL):** `ninja_core/hal.py` - Dynamic driver loading via `importlib`, validates against ABCs
- **CommandDispatcher:** Singleton that routes BLE & Web commands to HAL/Agent
- **ABC Interfaces:** `ninja_utils/interfaces.py` - `Sensor` (initialize/get_data/close) and `Actuator` (initialize/execute/off)
- **Driver Registry:** Maps driver names to module.class paths for dynamic loading

## File Structure (Root)
```
NinjaRobotPi0/
├── ninja_core/      # Orchestrator (HAL, Config, Agent, WebServer, Motion, etc.)
├── ninja_ble/       # BLE GATT service
├── ninja_utils/     # Shared utilities & ABCs (interfaces.py)
├── ninja_webapp/    # Web frontend
├── pi0servo/        # Servo library (rebuilt with velocity-based control)
├── pi0disp/         # Display library (ST7789V)
├── pi0buzzer/       # Buzzer library
├── pi0vl53l0x/      # Distance sensor library (rewritten)
├── pi0vl53l0x_bak/  # Backup of old VL53L0X lib
├── assets/          # Images, fonts, sounds
├── GEMINI.md        # AI development protocol
├── README.md        # Project README (EN/JA/ZH-TW)
├── DevelopmentGuide.md  # Full API reference (2265 lines)
├── DevelopmentLog.md    # Dev log (Dec 2025 - Feb 2026)
├── InstallationGuide.md # Complete setup guide
├── ProjectUpgradePlan.md # Driver upgrade plan
├── pyproject.toml       # Root workspace config
└── uv.lock
```

## Development Status
- **Phase 1 (Modularity):** ✅ Complete - Plugin HAL, dynamic loading, ABC validation
- **Phase 2 (Dual Connectivity):** ✅ Complete - BLE GATT + Web Server
- **Phase 3 (AI Agent):** ✅ Complete - Gemini NLP, emotions, movements, multilingual
- **Phase 4 (Code Platform):** ✅ Complete - Safe executor, NinjaCoder, API wrappers
- **Driver Upgrades:** pi0servo ✅ Complete, pi0vl53l0x ✅ Rewritten, pi0disp/pi0buzzer planned

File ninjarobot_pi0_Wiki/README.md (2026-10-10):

# NinjaRobotPi0 local knowledge

Read [the parent policy](../AGENTS.md) and [project workflow](docs/PROJECT_WORKFLOW.md).
Current full manuals:

- [InstallationGuide.md](raw/articles/ninjarobotpi0/2026-10-10-model-adapter/InstallationGuide.md)
- [DevelopmentGuide.md](raw/articles/ninjarobotpi0/2026-10-11-shutdown-voice-fixes/DevelopmentGuide.md)
- [DevelopmentLog.md](raw/notes/ninjarobotpi0/2026-10-11-shutdown-voice-fixes/DevelopmentLog.md)

The [knowledge map](project-knowledge.json) resolves active source versions and reviewed code.
Curated pages begin at [overview](wiki/overview.md). Registered raw originals are immutable.
This folder remains embedded in the robot Git repository; do not initialize another Git repository.
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

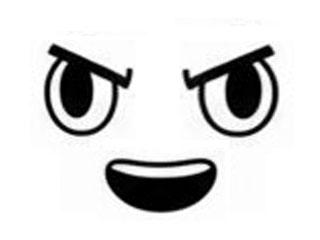
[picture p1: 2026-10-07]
assets/images/sample_face.jpg

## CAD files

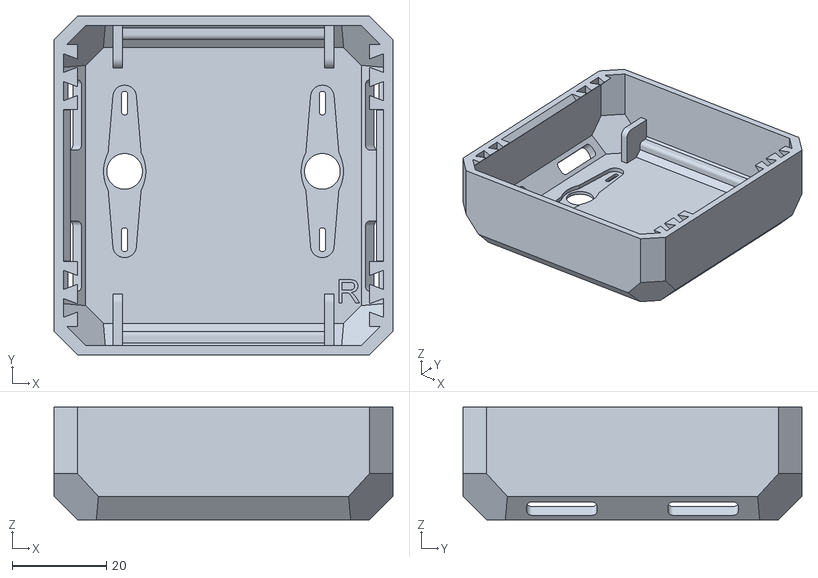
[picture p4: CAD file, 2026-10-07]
3Dmodels/NinjaV5/NinjaV5_Bottom.stl
72.0 x 72.0 x 24.0

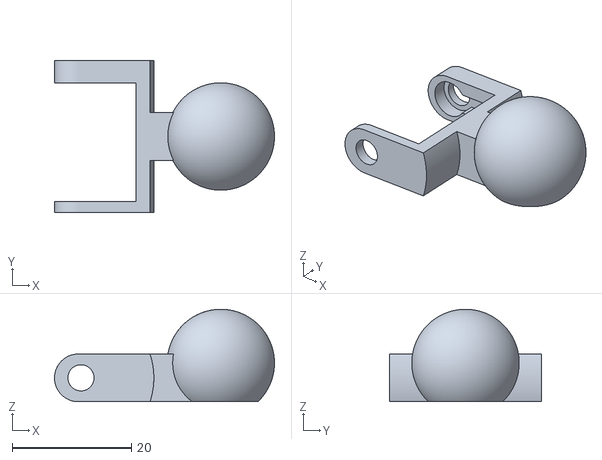
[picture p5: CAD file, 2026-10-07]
3Dmodels/Satsuke/SastukeV5_Arm_Left.stl
36.9 x 25.5 x 15.5

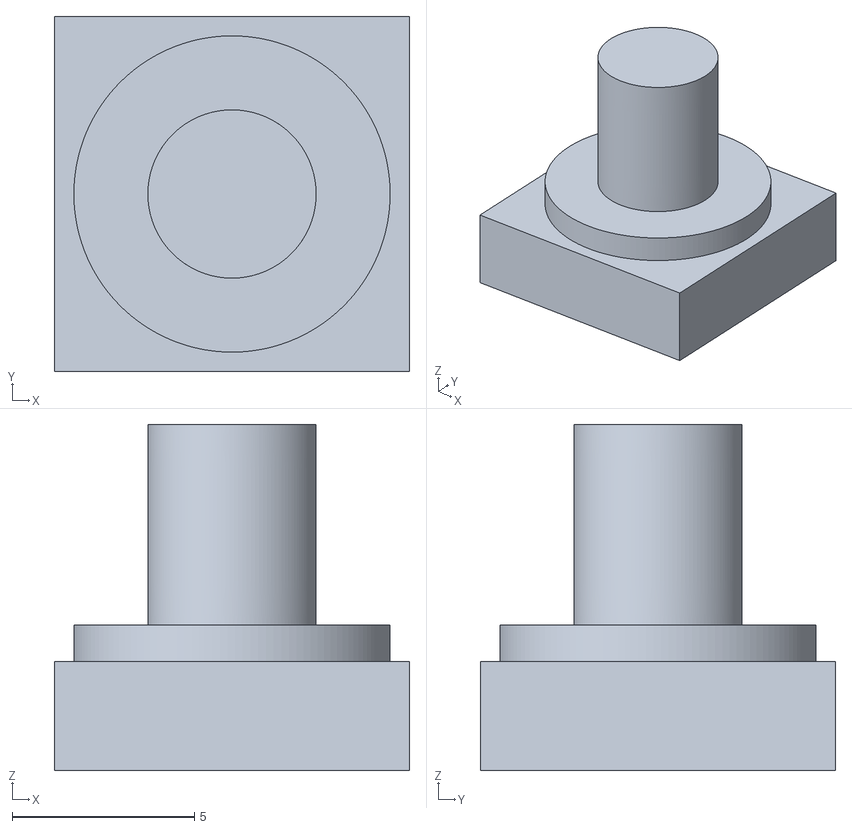
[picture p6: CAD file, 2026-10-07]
3Dmodels/Spider/SpiderV5_BodyServo_Pin.stl
9.75 x 9.76 x 9.51

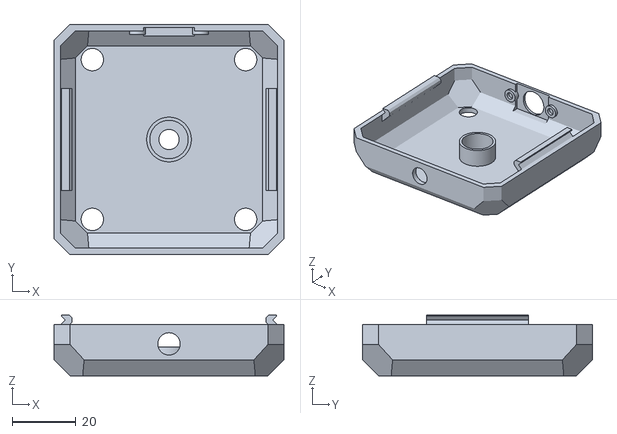
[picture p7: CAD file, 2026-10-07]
3Dmodels/NinjaV5/NinjaV5_Top.stl
72.0 x 72.0 x 19.0

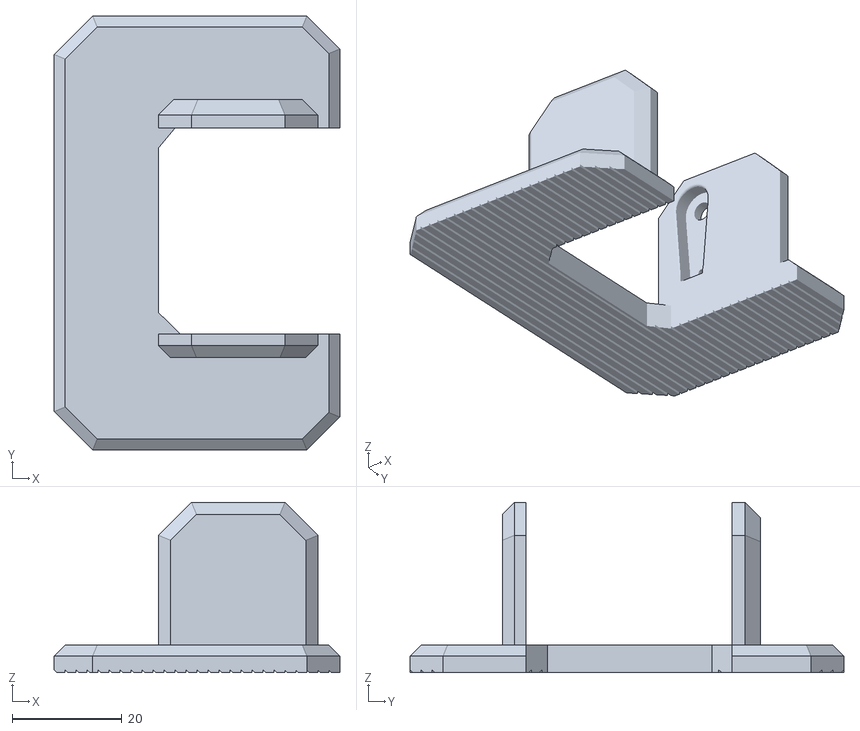
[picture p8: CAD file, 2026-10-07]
3Dmodels/Satsuke/SastukeV5_Feet_Right.stl
52.0 x 79.0 x 31.0

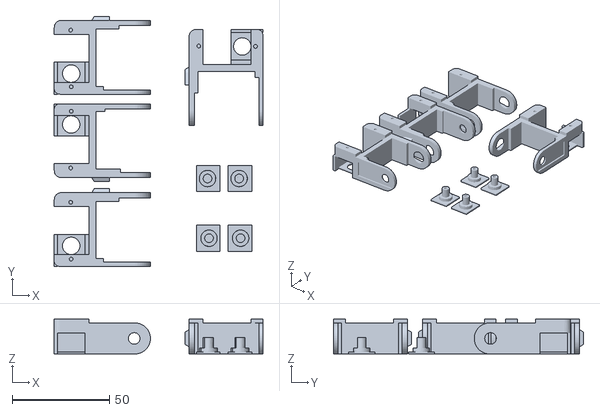
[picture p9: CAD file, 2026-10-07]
3Dmodels/Spider/SpiderV5_Legs_01.stl
107.5 x 128.6 x 18.0

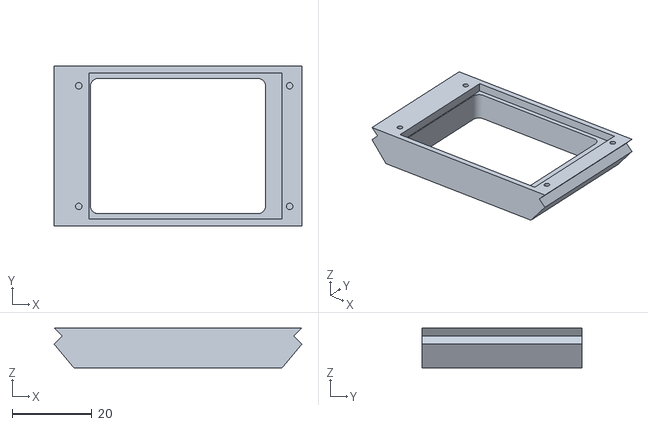
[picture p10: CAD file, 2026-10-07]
3Dmodels/NinjaV5/NinjaV5_LED.stl
62.0 x 40.0 x 10.0

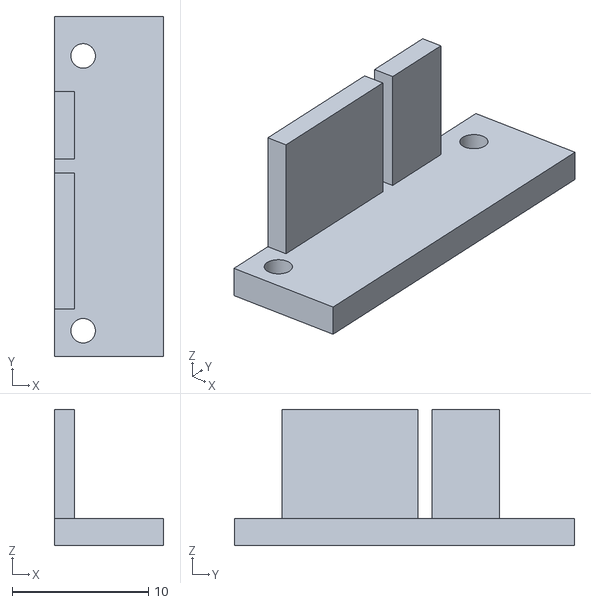
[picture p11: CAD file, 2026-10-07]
3Dmodels/Satsuke/SastukeV5_SeovoHolder_Left.stl
8.00 x 25.0 x 10.0

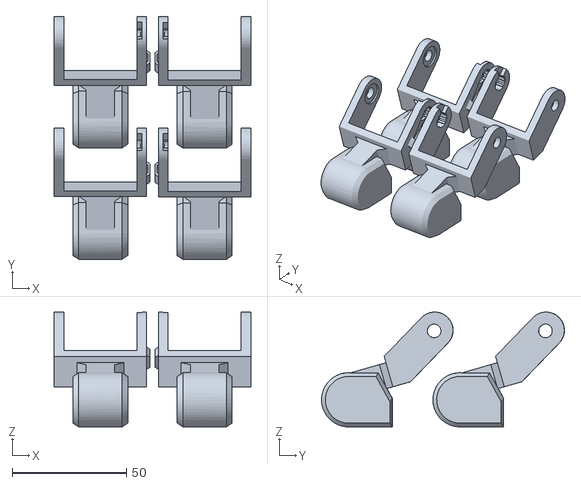
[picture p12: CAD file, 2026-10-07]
3Dmodels/Spider/SpiderV5_Feet_02.stl
86.1 x 106.3 x 50.2

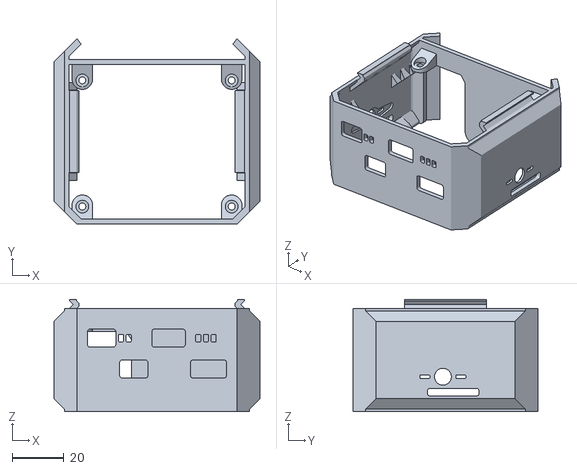
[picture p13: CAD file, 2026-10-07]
3Dmodels/NinjaV5/NinjaV5_Middle.stl
80.0 x 72.0 x 43.5

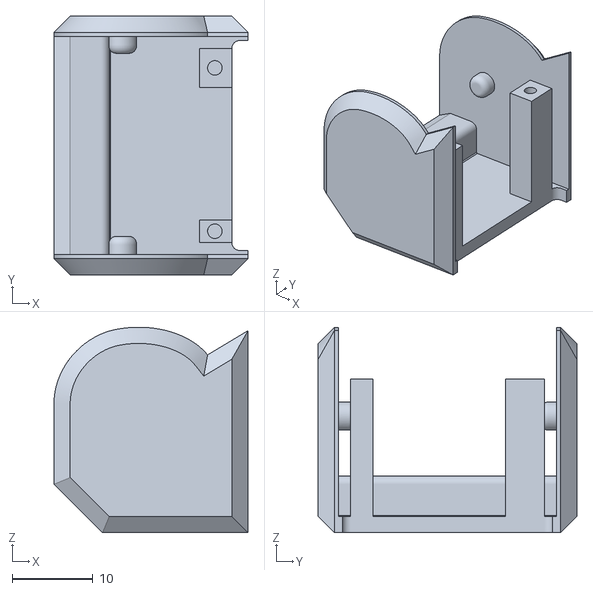
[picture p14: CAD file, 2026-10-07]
3Dmodels/Satsuke/SastukeV5_Shoulder_Left.stl
24.0 x 32.0 x 25.4

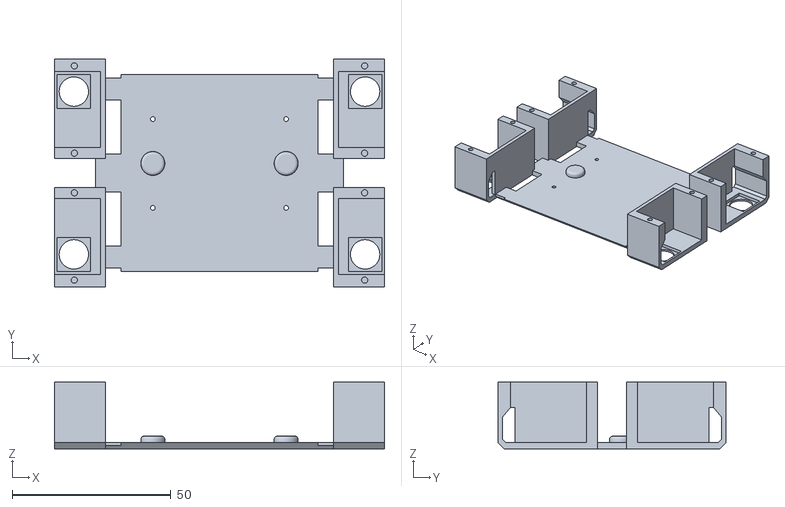
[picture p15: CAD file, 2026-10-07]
3Dmodels/Spider/SpiderV5_LegHolder.stl
104.0 x 72.0 x 21.0

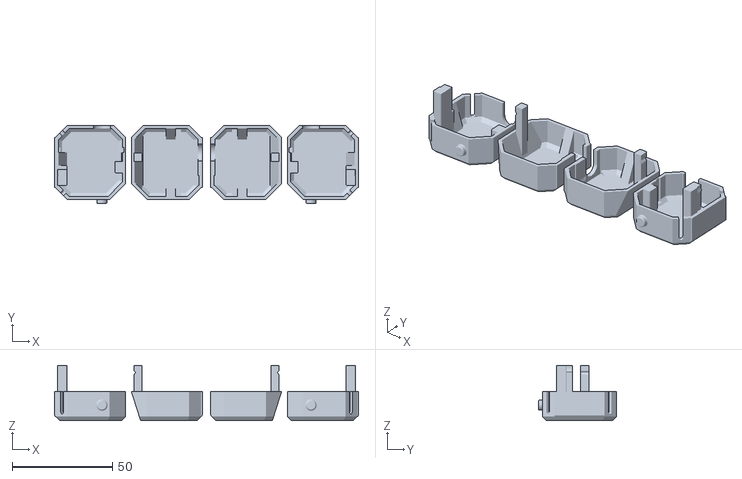
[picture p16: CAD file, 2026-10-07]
3Dmodels/Satsuke/SastukeV5_Legs.stl
151.8 x 39.0 x 27.5

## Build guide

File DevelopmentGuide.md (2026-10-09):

# DevelopmentGuide

[Open the current complete version](ninjarobot_pi0_Wiki/raw/articles/ninjarobotpi0/2026-10-09-builtins/DevelopmentGuide.md).

This file preserves existing public links. Full manuals live as immutable versions in the wiki.

日本語: 上記リンクから最新版を開いてください。
繁體中文：請由上方連結開啟完整最新版。

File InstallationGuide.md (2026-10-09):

# InstallationGuide

[Open the current complete version](ninjarobot_pi0_Wiki/raw/articles/ninjarobotpi0/2026-10-09-builtins/InstallationGuide.md).

This file preserves existing public links. Full manuals live as immutable versions in the wiki.

日本語: 上記リンクから最新版を開いてください。
繁體中文：請由上方連結開啟完整最新版。

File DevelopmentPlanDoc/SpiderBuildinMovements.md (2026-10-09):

# NinjaRobotPi0 Spider: OTTO waypoint movement library

Date: 2026-10-09. Status: implemented as an **opt-in, offline-generated JSON pack**; host validation only. No existing movement-control function, driver, API, runtime config, or calibration was changed. This library follows the corrected joint mapping supplied by the owner.

This document describes what works with the current executor. [Pi0BuildinMovementsRefinement.md](Pi0BuildinMovementsRefinement.md) separately evaluates a future timed/oscillator controller; none of its proposed fields or functions are implemented here.

## 1. Movement System Overview

### Existing execution path

`config.json` contains a `movements` object: each name maps to an ordered list of steps. `NinjaConfig.movements` is `Dict[str, list]`, so the config model validates that outer shape but does **not** deeply validate every step. The recorder writes steps, saves the configuration, and the controller reads `config.movements`. The web movement list/execute endpoints and movement CLI use the same controller. There is no automatic directory scan for the new pack.

```mermaid
flowchart TD
  A["Existing config.json: movements"] --> B["load_config / NinjaConfig"]
  B --> C["MovementController.execute_movement(name)"]
  C --> D["Ordered step: moves, speed, optional per_servo_speeds"]
  D --> E["move_servos: match GPIO keys to driver pin order"]
  E --> F["ServoGroup.move_all_sync"]
  F --> G["Independent per-servo travel times and easing"]
  G --> H["Servo.set_angle: calibrated pulse output"]
  G --> I["Wait for slowest servo, then next step"]
```

The pack is [ninja_core/movements/spider_otto.json](../ninja_core/movements/spider_otto.json). Its only root keys are existing fields `robot_type: "spider"` and `movements`. It has no pretend calibration profile. It loads through `load_config(path)` as a config fragment, but cannot operate an actual robot on its own because it deliberately supplies no servo calibration/pins. It is not installed or merged into the live configuration by this task.

### Current behavior, verified from code

| Aspect | Actual behavior |
|---|---|
| `moves` | Object of string GPIO numbers to numeric angles; executor converts keys to int |
| `speed` | Required by `execute_movement`; use existing `F`, `M`, `S` modes |
| `per_servo_speeds` | Optional string-GPIO-to-mode object, overrides speed for a commanded servo |
| Omitted GPIO | Target is `None`; that servo is skipped, retaining its previous command/state |
| Unknown GPIO | This controller silently omits it because it iterates driver pins; the pack tests ensure exact pins, but deployment must have all eight |
| Multi-servo step | Starts a shared software loop; each servo has its own duration; not synchronized arrival |
| Steps | Executed sequentially; next starts after the longest duration of the current step |
| Easing | One step: in/out cubic; first of many: in cubic; middle: linear; last: out cubic |
| Duration | Calculated from angular distance, calibration speed percentage, and F/M/S multiplier |
| Delay/repeat/oscillator | No fields consumed by the current executor; adding such JSON keys would not implement them |
| Final state | Last targets remain commanded; executor does not automatically home or release |

The driver uses a 0.01 s update interval. Its nominal calculation is:

`velocity = 600 × (calibration.speed / 100) × mode_multiplier` degrees/second,

where F=1, M=0.75, S=0.5; `duration = abs(target − previous_angle) / velocity`. These are driver calculations, not measured motor performance. Cubic easing changes instantaneous speed: that formula is not a hard peak-velocity limit. A missing cached angle falls back to driver pulse-to-angle reading and then calibration center, not a joint encoder.

Sources: [config.py](../ninja_core/src/ninja_core/config.py), `NinjaConfig`, `load_config`, `save_config`; [movement_controller.py](../ninja_core/src/ninja_core/movement_controller.py), `move_servos` and `execute_movement`; [multi_servos.py](../pi0servo/src/pi0servo/core/multi_servos.py), `move_all_sync`; [calculator.py](../pi0servo/src/pi0servo/motion/calculator.py), `calculate_duration`.

## 2. How to Control Servos

These are compatible **movement entries inside `config.movements`**, not commands automatically executed by reading this document. Numeric angles are targets, not measured joint angles. The examples use M, the target system's existing default mode; it is not a conversion of an OTTO period.

### One servo

```json
{
  "example_one": [
    {"moves": {"20": 20}, "speed": "M"}
  ]
}
```

Only GPIO20 is commanded. Other servos retain their previous state; an omitted servo is not automatically attached or centered.

### Several servos in one step, with an optional override

```json
{
  "example_group": [
    {
      "moves": {"20": 20, "21": -20},
      "speed": "S",
      "per_servo_speeds": {"21": "F"}
    }
  ]
}
```

GPIO20 uses Slow and GPIO21 Fast. Each advances from its existing angle; the faster one may finish first. The controller waits for both before returning. Speed overrides on pins absent from `moves` do not command those pins.

### Ordered sequence

```json
{
  "example_sequence": [
    {"moves": {"20": 20, "21": -20}, "speed": "M"},
    {"moves": {"20": 0}, "speed": "M"}
  ]
}
```

GPIO21 stays at its previous −20° command during the second step. There is no dwell between these steps. Repeating the same target does not create a reliable pause: the driver sees zero angular distance and zero nominal duration.

### Loading the library without activating hardware

From the robot repository, this standard-library snippet creates a **preview file only**, preserving other configuration fields and refusing name collisions. It does not import the HAL or operate hardware. Inspect the result locally; it can contain existing private settings and must not be published.

```python
import json
from pathlib import Path

existing = json.loads(Path("config.json").read_text())
pack = json.loads(Path("ninja_core/movements/spider_otto.json").read_text())
if existing.get("robot_type") != "spider":
    raise ValueError("Use a configured Spider profile; do not change another robot implicitly")
missing = set(map(str, range(20, 28))) - set(existing.get("servos", {}).get("calibration", {}))
if missing:
    raise ValueError("Missing servo configuration for one or more Spider GPIOs")
# Convert the source pack names to the names used in this document.
incoming = {
    "spider_" + name.removeprefix("spider_otto_"): steps
    for name, steps in pack["movements"].items()
}
incoming["Poweroff"] = [{
    "speed": "S",
    "moves": {"20": -90, "21": 90, "22": 90, "23": -90,
              "24": 90, "25": -90, "26": -90, "27": 90},
    "per_servo_speeds": {}
}]
current = existing.setdefault("movements", {})
if set(current) & set(incoming):
    raise ValueError("Resolve movement-name collisions before merging")
current.update(incoming)
with Path("config-spider-preview.json").open("x") as output:
    json.dump(existing, output, indent=2)
```

Presence of calibration keys is not proof of physical calibration. Runtime uses `servo.json` through the HAL's `ConfigManager`, so inspect actual pulse endpoints, angle bounds, speed limits, mounting, and all eight connected pins before any later activation. Replacing the live config/restarting the server is a separate deliberate deployment step, not performed here. The library does not automatically become available to CLI/web/AI simply by existing in its directory.

## 3. Spider Hardware and Servo Mapping

BCM GPIO numbers below are **not physical header pin numbers or list indices**. Joint labels come from the owner's corrected mapping. Current Pi0 defaults independently support GPIO20–27; no inspected Pi0 code/manual binds those numbers to different named hips/feet. The hardware placement therefore remains owner-specified rather than physically measured in this task.

| Pi0 BCM GPIO | Physical joint | OTTO ID | Source nominal range | Target nominal range |
|---|---|---|---|---|
| 20 | Left rear hip | S5 | 0…180° | −90…+90° |
| 21 | Right rear hip | S4 | 0…180° | −90…+90° |
| 22 | Left rear foot | S7 | 0…180° | −90…+90° |
| 23 | Right rear foot | S6 | 0…180° | −90…+90° |
| 24 | Left front hip | S1 | 0…180° | −90…+90° |
| 25 | Right front hip | S0 | 0…180° | −90…+90° |
| 26 | Left front foot | S3 | 0…180° | −90…+90° |
| 27 | Right front foot | S2 | 0…180° | −90…+90° |

The source-index-to-GPIO vector is `[25,24,27,26,21,20,23,22]`. The target controller orders commands by its driver pin list, so JSON insertion order must never be treated as physical servo identity. Tests deliberately shuffle that pin list.

The existing InstallationGuide specifies an external servo supply and common ground with the Pi, rather than powering the servo group from the Pi's 5 V header rail. The source OTTO supply diagram does not establish an adequate Pi0 supply current. No wiring, power, mesh, or mounting test was performed in this implementation task.

Runtime calibration comes from [hal.py](../ninja_core/src/ninja_core/hal.py), `_init_servos`, and [ConfigManager.get_calibration](../pi0servo/src/pi0servo/config/config_manager.py). Pi0's core config and standalone driver have different default pulse behavior: the driver dataclass's absent calibration uses 1500/1500/1500, while a present but incomplete config entry can default to 500/1500/2500. Neither is evidence of a calibrated physical build. Do not substitute source EEPROM trim or nominal defaults for measured Pi0 calibration.

## 4. Angle Conversion

The implemented nominal conversion is:

`target_GPIO[source_id] = source_logical_angle − 90°`.

Thus 90→0, 45→−45, 110→20. The untrimmed home vector becomes:

```json
{
  "moves": {"20": 20, "21": -20, "22": 0, "23": 0, "24": -20, "25": 20, "26": 0, "27": 0},
  "speed": "M"
}
```

This is an OTTO-derived stance, **not** Pi0's all-zero center pose.

### Corrections intentionally not assumed

- The OTTO sketch reverses S2 after initial home: its actual motor write is `180−(q2+trim2)`. That is evidence about the source build, not evidence that GPIO27 on the owner's Pi0 should be reversed. This nominal port does not copy that mounting-specific correction. For example, waveHAND's phase-zero q2=30 becomes GPIO27=−60 here; literal source motor-write translation with zero trim would be +60. Direction compatibility is therefore explicitly unverified.
- Source EEPROM trims are unknown and not portable; generated values use zero source trim. Pi0 calibration independently maps signed angles to pulse widths. Home's source double-trim bug is not imported.
- Only hello's logical S1 wave falls below the nominal source range. The generator clamps q to 0…180 before subtracting 90, explicitly giving −90 at its lower endpoint; otherwise that source −10 would become −100. This is a documented range adaptation. It is not evidence that a −90° physical endpoint is mechanically safe.
- No generic `invert`, `offset`, or `duration` fields have been added to the existing JSON schema.

The driver clamps to its configured angular bounds and interpolates between calibrated pulse endpoints on either side of center. Its cached `last_angle` is the requested angle, which may differ from the clamped physical command. Narrower robot limits can therefore alter a movement even though every pack value passes the nominal ±90 check.

## 5. Complete Built-in Movement Library

### Translation convention and fidelity

There are **19 OTTO-derived entries covering 16 original movement/pose functions**, plus the owner-supplied **`Poweroff`** pose: **20 documented movements and 566 total steps**. Run, walk, and omniWalk each have two entries for their direction/side variants. The omni defaults produce identical waveform samples; those names preserve source call selection, not distinct physical trajectories. Internal helpers are not separate movements.

Every periodic entry represents **one finite logical cycle**, with 36 equal phase intervals plus the initial endpoint: 37 waypoints. Each waypoint commands all eight mapped servos. This 10° phase sampling is an explicit approximation choice, not OTTO's refresh interval. Targets use `O + A sin(2πct/P + phase)` sampled by phase, rounded to 0.001°. For walk the foot frequency multiplier c is 2. That gives 18 samples per foot cycle. No source `steps` argument is treated as a reliable stop condition; most OTTO functions ignore it.

The JSON cannot carry the listed source periods: each step uses native M and its actual duration depends on distances, previous pose, calibration, and easing. Intermediate joint phases can diverge because servos arrive independently. These definitions preserve **ordered target poses**, not exact temporal coordination, duty cycle, velocity, foot support, or continuous locomotion. They are not physical qualification for floor walking.

All sine entries finish at the mathematical phase-zero endpoint after one cycle, holding the final command rather than automatically returning home. OTTO normally keeps oscillating. Repeated invocations add first/last-step easing and are not seamless oscillator continuation. Startup transition comes from the robot's existing position; no unrequested neutral step is inserted.

### Complete coverage table

The 19 OTTO-derived names below use prefix `spider_`. The linked source pack still uses `spider_otto_`; this document intentionally uses the renamed keys. The preview merge in section 2 converts that prefix. `Poweroff` is an additional document-defined movement and keeps its exact case-sensitive name. “Validated” means schema-shape, numerical, mapping, and mocked-executor validation; **all hardware tests remain pending**.

| Name suffix | Original function / purpose | Phases and varying joints | Source period or waits | Adaptation / status |
|---|---|---|---|---|
| home | home: reference stance | 1 all-servo pose | Immediate source write | Nominal pose; no source detach/double trim; validated |
| run_forward | run(0): forward-labeled gait | 37; all joints | 550 ms cycle | Finite sampled cycle; validated |
| run_backward | run(1): reverse-labeled gait | 37; all joints, opposite hip phases | 550 ms cycle | Direction variant; validated |
| turn_left | turnL | 37; all joints | 550 ms cycle | Opposed hip phases; validated |
| turn_right | turnR | 37; all joints | 550 ms cycle | Opposite turn pattern; validated |
| dance | dance: staggered foot waves | 37; feet vary, hips fixed | Serial 1000 ms; API default 2000 | Serial angular pattern; no period preservation; validated |
| front_back | frontBack: coordinated hip/foot rocking | 37; all joints | Serial 750 ms; API default 2000 | Same angles for both period choices; validated |
| up_down | upDown: foot bending | 37; feet vary, hips fixed | 500 ms cycle | Body-height effect unverified; validated |
| push_up | pushUp: front-foot bending | 37; S2/S3 vary, other targets fixed | 5000 ms cycle | Rear hips at 25/155 source degrees; validated |
| wave_hand | waveHAND | 37; only S2/GPIO27 varies | 700 ms cycle | Negative amplitude retained; no unverified target inversion; validated |
| hide | Hide: folded-like pose | 1 all-servo pose | Source zero amplitudes, nominal T=700 | Constant target, no continuous rewrite; validated |
| moonwalk_left | moonwalkL | 37; four feet vary at staggered phases | 2000 ms cycle | Includes 120°/290° phases; validated |
| omni_true | omniWalk(true,1000,2) | 37; all joints | 1000 ms cycle | Source default f=2, not silently changed to f=1; validated |
| omni_false | omniWalk(false,1000,2) | 37; all joints | 1000 ms cycle | Equivalent default samples to omni_true; validated |
| walk_forward | walk(1) | 37; feet cycle twice per hip cycle | 550 ms hips, 275 feet | All joints updated, reflecting pause's refresh; finite cycle, not default four-cycle blocking loop; validated |
| walk_backward | walk(0) | 37; reversed hip phases | Same periods | Direction variant; validated |
| jump | jump: folded/stretch/home | 3 all-servo poses | Source waits 1000,100 ms | Waits unsupported/omitted; target interpolates instead of immediate writes; validated |
| scared | scared: stretch/folded/home | 3 all-servo poses | Source waits 2000,100 ms | Same timing loss; reversed pose order; validated |
| hello | hello: small helper writes and front-left wave | 2 helper-derived waypoints + 37 wave samples | Wave 350 ms; helper total duration uptime-dependent | Partial, state-dependent source cannot be reproduced exactly; numerical/loader validated |
| Poweroff | Owner-supplied shutdown pose, not an OTTO function | 1 all-servo pose | Native S; distance-derived duration | Exact case-sensitive shutdown lookup name; no physical validation |

`walk`, `moonwalkL`, and `hello` are independently callable source methods even though not exposed by OTTO's gait menu. Four expression wrappers only add home poses/display changes and are not duplicated as movement trajectories. Autonomous obstacle/dance modes are policies composing movements and sensors, not additional independently defined joint patterns; their scheduling is outside this finite JSON pack.

Arbitrary continuous parameter values (steps/T/turn_factor) are not infinitely enumerated. The pack covers the named/default variants above. For example, f=0 or f=1 in omniWalk requires regenerating parameter-derived poses for an explicitly chosen variant; the existing JSON cannot accept a runtime factor. Source formulas remain available in the generator and OTTO reference.

### Complete copyable JSON for every movement

Each block below is a complete JSON **configuration fragment** containing one named movement. Copy the named `spider_*` or `Poweroff` entry into the `movements` object of your existing Spider `config.json`; preserve your other configuration fields, servo calibration and other movements. Do not replace your full robot configuration with a fragment. The preview-merge example in section 2 shows how to merge the complete library without activating hardware.

After deliberately loading the updated configuration in your normal Pi0 runtime, select the exact movement name in the existing movement tool or web movement list. Each invocation plays the listed sequence once. These blocks contain every waypoint and all eight GPIO targets; there are no omitted steps or placeholders. The 19 OTTO-derived sequences have identical step values to `ninja_core/movements/spider_otto.json`, with names changed from `spider_otto_*` to `spider_*`. The additional `Poweroff` definition is provided below and is not in that source pack.

The OTTO-derived steps use native `M` speed; `Poweroff` uses native `S`. The JSON reproduces the translated target-pose sequence; the existing executor does not preserve OTTO's exact cycle periods or pauses. Use the calibrated Spider mapping described above; physical direction and clearance remain unverified. In particular, jump/scared omit source waits and hello remains a partial adaptation.

#### 1. spider_home

Complete sequence: 1 step.

```json
{
  "robot_type": "spider",
  "movements": {
    "spider_home": [
      {"moves": {"20": 20.0, "21": -20.0, "22": 0.0, "23": 0.0, "24": -20.0, "25": 20.0, "26": 0.0, "27": 0.0}, "speed": "M"}
    ]
  }
}
```

#### 2. spider_run_forward

Complete sequence: 37 steps.

```json
{
  "robot_type": "spider",
  "movements": {
    "spider_run_forward": [
      {"moves": {"20": 15.0, "21": -15.0, "22": 15.0, "23": 15.0, "24": -15.0, "25": 15.0, "26": 15.0, "27": 15.0}, "speed": "M"},
      {"moves": {"20": 12.395, "21": -17.605, "22": 14.772, "23": 14.772, "24": -12.395, "25": 17.605, "26": 14.772, "27": 14.772}, "speed": "M"},
      {"moves": {"20": 9.87, "21": -20.13, "22": 14.095, "23": 14.095, "24": -9.87, "25": 20.13, "26": 14.095, "27": 14.095}, "speed": "M"},
      {"moves": {"20": 7.5, "21": -22.5, "22": 12.99, "23": 12.99, "24": -7.5, "25": 22.5, "26": 12.99, "27": 12.99}, "speed": "M"},
      {"moves": {"20": 5.358, "21": -24.642, "22": 11.491, "23": 11.491, "24": -5.358, "25": 24.642, "26": 11.491, "27": 11.491}, "speed": "M"},
      {"moves": {"20": 3.509, "21": -26.491, "22": 9.642, "23": 9.642, "24": -3.509, "25": 26.491, "26": 9.642, "27": 9.642}, "speed": "M"},
      {"moves": {"20": 2.01, "21": -27.99, "22": 7.5, "23": 7.5, "24": -2.01, "25": 27.99, "26": 7.5, "27": 7.5}, "speed": "M"},
      {"moves": {"20": 0.905, "21": -29.095, "22": 5.13, "23": 5.13, "24": -0.905, "25": 29.095, "26": 5.13, "27": 5.13}, "speed": "M"},
      {"moves": {"20": 0.228, "21": -29.772, "22": 2.605, "23": 2.605, "24": -0.228, "25": 29.772, "26": 2.605, "27": 2.605}, "speed": "M"},
      {"moves": {"20": 0.0, "21": -30.0, "22": 0.0, "23": 0.0, "24": 0.0, "25": 30.0, "26": 0.0, "27": 0.0}, "speed": "M"},
      {"moves": {"20": 0.228, "21": -29.772, "22": -2.605, "23": -2.605, "24": -0.228, "25": 29.772, "26": -2.605, "27": -2.605}, "speed": "M"},
      {"moves": {"20": 0.905, "21": -29.095, "22": -5.13, "23": -5.13, "24": -0.905, "25": 29.095, "26": -5.13, "27": -5.13}, "speed": "M"},
      {"moves": {"20": 2.01, "21": -27.99, "22": -7.5, "23": -7.5, "24": -2.01, "25": 27.99, "26": -7.5, "27": -7.5}, "speed": "M"},
      {"moves": {"20": 3.509, "21": -26.491, "22": -9.642, "23": -9.642, "24": -3.509, "25": 26.491, "26": -9.642, "27": -9.642}, "speed": "M"},
      {"moves": {"20": 5.358, "21": -24.642, "22": -11.491, "23": -11.491, "24": -5.358, "25": 24.642, "26": -11.491, "27": -11.491}, "speed": "M"},
      {"moves": {"20": 7.5, "21": -22.5, "22": -12.99, "23": -12.99, "24": -7.5, "25": 22.5, "26": -12.99, "27": -12.99}, "speed": "M"},
      {"moves": {"20": 9.87, "21": -20.13, "22": -14.095, "23": -14.095, "24": -9.87, "25": 20.13, "26": -14.095, "27": -14.095}, "speed": "M"},
      {"moves": {"20": 12.395, "21": -17.605, "22": -14.772, "23": -14.772, "24": -12.395, "25": 17.605, "26": -14.772, "27": -14.772}, "speed": "M"},
      {"moves": {"20": 15.0, "21": -15.0, "22": -15.0, "23": -15.0, "24": -15.0, "25": 15.0, "26": -15.0, "27": -15.0}, "speed": "M"},
      {"moves": {"20": 17.605, "21": -12.395, "22": -14.772, "23": -14.772, "24": -17.605, "25": 12.395, "26": -14.772, "27": -14.772}, "speed": "M"},
      {"moves": {"20": 20.13, "21": -9.87, "22": -14.095, "23": -14.095, "24": -20.13, "25": 9.87, "26": -14.095, "27": -14.095}, "speed": "M"},
      {"moves": {"20": 22.5, "21": -7.5, "22": -12.99, "23": -12.99, "24": -22.5, "25": 7.5, "26": -12.99, "27": -12.99}, "speed": "M"},
      {"moves": {"20": 24.642, "21": -5.358, "22": -11.491, "23": -11.491, "24": -24.642, "25": 5.358, "26": -11.491, "27": -11.491}, "speed": "M"},
      {"moves": {"20": 26.491, "21": -3.509, "22": -9.642, "23": -9.642, "24": -26.491, "25": 3.509, "26": -9.642, "27": -9.642}, "speed": "M"},
      {"moves": {"20": 27.99, "21": -2.01, "22": -7.5, "23": -7.5, "24": -27.99, "25": 2.01, "26": -7.5, "27": -7.5}, "speed": "M"},
      {"moves": {"20": 29.095, "21": -0.905, "22": -5.13, "23": -5.13, "24": -29.095, "25": 0.905, "26": -5.13, "27": -5.13}, "speed": "M"},
      {"moves": {"20": 29.772, "21": -0.228, "22": -2.605, "23": -2.605, "24": -29.772, "25": 0.228, "26": -2.605, "27": -2.605}, "speed": "M"},
      {"moves": {"20": 30.0, "21": 0.0, "22": 0.0, "23": 0.0, "24": -30.0, "25": 0.0, "26": 0.0, "27": 0.0}, "speed": "M"},
      {"moves": {"20": 29.772, "21": -0.228, "22": 2.605, "23": 2.605, "24": -29.772, "25": 0.228, "26": 2.605, "27": 2.605}, "speed": "M"},
      {"moves": {"20": 29.095, "21": -0.905, "22": 5.13, "23": 5.13, "24": -29.095, "25": 0.905, "26": 5.13, "27": 5.13}, "speed": "M"},
      {"moves": {"20": 27.99, "21": -2.01, "22": 7.5, "23": 7.5, "24": -27.99, "25": 2.01, "26": 7.5, "27": 7.5}, "speed": "M"},
      {"moves": {"20": 26.491, "21": -3.509, "22": 9.642, "23": 9.642, "24": -26.491, "25": 3.509, "26": 9.642, "27": 9.642}, "speed": "M"},
      {"moves": {"20": 24.642, "21": -5.358, "22": 11.491, "23": 11.491, "24": -24.642, "25": 5.358, "26": 11.491, "27": 11.491}, "speed": "M"},
      {"moves": {"20": 22.5, "21": -7.5, "22": 12.99, "23": 12.99, "24": -22.5, "25": 7.5, "26": 12.99, "27": 12.99}, "speed": "M"},
      {"moves": {"20": 20.13, "21": -9.87, "22": 14.095, "23": 14.095, "24": -20.13, "25": 9.87, "26": 14.095, "27": 14.095}, "speed": "M"},
      {"moves": {"20": 17.605, "21": -12.395, "22": 14.772, "23": 14.772, "24": -17.605, "25": 12.395, "26": 14.772, "27": 14.772}, "speed": "M"},
      {"moves": {"20": 15.0, "21": -15.0, "22": 15.0, "23": 15.0, "24": -15.0, "25": 15.0, "26": 15.0, "27": 15.0}, "speed": "M"}
    ]
  }
}
```

#### 3. spider_run_backward

Complete sequence: 37 steps.

```json
{
  "robot_type": "spider",
  "movements": {
    "spider_run_backward": [
      {"moves": {"20": 15.0, "21": -15.0, "22": 15.0, "23": 15.0, "24": -15.0, "25": 15.0, "26": 15.0, "27": 15.0}, "speed": "M"},
      {"moves": {"20": 17.605, "21": -12.395, "22": 14.772, "23": 14.772, "24": -17.605, "25": 12.395, "26": 14.772, "27": 14.772}, "speed": "M"},
      {"moves": {"20": 20.13, "21": -9.87, "22": 14.095, "23": 14.095, "24": -20.13, "25": 9.87, "26": 14.095, "27": 14.095}, "speed": "M"},
      {"moves": {"20": 22.5, "21": -7.5, "22": 12.99, "23": 12.99, "24": -22.5, "25": 7.5, "26": 12.99, "27": 12.99}, "speed": "M"},
      {"moves": {"20": 24.642, "21": -5.358, "22": 11.491, "23": 11.491, "24": -24.642, "25": 5.358, "26": 11.491, "27": 11.491}, "speed": "M"},
      {"moves": {"20": 26.491, "21": -3.509, "22": 9.642, "23": 9.642, "24": -26.491, "25": 3.509, "26": 9.642, "27": 9.642}, "speed": "M"},
      {"moves": {"20": 27.99, "21": -2.01, "22": 7.5, "23": 7.5, "24": -27.99, "25": 2.01, "26": 7.5, "27": 7.5}, "speed": "M"},
      {"moves": {"20": 29.095, "21": -0.905, "22": 5.13, "23": 5.13, "24": -29.095, "25": 0.905, "26": 5.13, "27": 5.13}, "speed": "M"},
      {"moves": {"20": 29.772, "21": -0.228, "22": 2.605, "23": 2.605, "24": -29.772, "25": 0.228, "26": 2.605, "27": 2.605}, "speed": "M"},
      {"moves": {"20": 30.0, "21": 0.0, "22": 0.0, "23": 0.0, "24": -30.0, "25": 0.0, "26": 0.0, "27": 0.0}, "speed": "M"},
      {"moves": {"20": 29.772, "21": -0.228, "22": -2.605, "23": -2.605, "24": -29.772, "25": 0.228, "26": -2.605, "27": -2.605}, "speed": "M"},
      {"moves": {"20": 29.095, "21": -0.905, "22": -5.13, "23": -5.13, "24": -29.095, "25": 0.905, "26": -5.13, "27": -5.13}, "speed": "M"},
      {"moves": {"20": 27.99, "21": -2.01, "22": -7.5, "23": -7.5, "24": -27.99, "25": 2.01, "26": -7.5, "27": -7.5}, "speed": "M"},
      {"moves": {"20": 26.491, "21": -3.509, "22": -9.642, "23": -9.642, "24": -26.491, "25": 3.509, "26": -9.642, "27": -9.642}, "speed": "M"},
      {"moves": {"20": 24.642, "21": -5.358, "22": -11.491, "23": -11.491, "24": -24.642, "25": 5.358, "26": -11.491, "27": -11.491}, "speed": "M"},
      {"moves": {"20": 22.5, "21": -7.5, "22": -12.99, "23": -12.99, "24": -22.5, "25": 7.5, "26": -12.99, "27": -12.99}, "speed": "M"},
      {"moves": {"20": 20.13, "21": -9.87, "22": -14.095, "23": -14.095, "24": -20.13, "25": 9.87, "26": -14.095, "27": -14.095}, "speed": "M"},
      {"moves": {"20": 17.605, "21": -12.395, "22": -14.772, "23": -14.772, "24": -17.605, "25": 12.395, "26": -14.772, "27": -14.772}, "speed": "M"},
      {"moves": {"20": 15.0, "21": -15.0, "22": -15.0, "23": -15.0, "24": -15.0, "25": 15.0, "26": -15.0, "27": -15.0}, "speed": "M"},
      {"moves": {"20": 12.395, "21": -17.605, "22": -14.772, "23": -14.772, "24": -12.395, "25": 17.605, "26": -14.772, "27": -14.772}, "speed": "M"},
      {"moves": {"20": 9.87, "21": -20.13, "22": -14.095, "23": -14.095, "24": -9.87, "25": 20.13, "26": -14.095, "27": -14.095}, "speed": "M"},
      {"moves": {"20": 7.5, "21": -22.5, "22": -12.99, "23": -12.99, "24": -7.5, "25": 22.5, "26": -12.99, "27": -12.99}, "speed": "M"},
      {"moves": {"20": 5.358, "21": -24.642, "22": -11.491, "23": -11.491, "24": -5.358, "25": 24.642, "26": -11.491, "27": -11.491}, "speed": "M"},
      {"moves": {"20": 3.509, "21": -26.491, "22": -9.642, "23": -9.642, "24": -3.509, "25": 26.491, "26": -9.642, "27": -9.642}, "speed": "M"},
      {"moves": {"20": 2.01, "21": -27.99, "22": -7.5, "23": -7.5, "24": -2.01, "25": 27.99, "26": -7.5, "27": -7.5}, "speed": "M"},
      {"moves": {"20": 0.905, "21": -29.095, "22": -5.13, "23": -5.13, "24": -0.905, "25": 29.095, "26": -5.13, "27": -5.13}, "speed": "M"},
      {"moves": {"20": 0.228, "21": -29.772, "22": -2.605, "23": -2.605, "24": -0.228, "25": 29.772, "26": -2.605, "27": -2.605}, "speed": "M"},
      {"moves": {"20": 0.0, "21": -30.0, "22": 0.0, "23": 0.0, "24": 0.0, "25": 30.0, "26": 0.0, "27": 0.0}, "speed": "M"},
      {"moves": {"20": 0.228, "21": -29.772, "22": 2.605, "23": 2.605, "24": -0.228, "25": 29.772, "26": 2.605, "27": 2.605}, "speed": "M"},
      {"moves": {"20": 0.905, "21": -29.095, "22": 5.13, "23": 5.13, "24": -0.905, "25": 29.095, "26": 5.13, "27": 5.13}, "speed": "M"},
      {"moves": {"20": 2.01, "21": -27.99, "22": 7.5, "23": 7.5, "24": -2.01, "25": 27.99, "26": 7.5, "27": 7.5}, "speed": "M"},
      {"moves": {"20": 3.509, "21": -26.491, "22": 9.642, "23": 9.642, "24": -3.509, "25": 26.491, "26": 9.642, "27": 9.642}, "speed": "M"},
      {"moves": {"20": 5.358, "21": -24.642, "22": 11.491, "23": 11.491, "24": -5.358, "25": 24.642, "26": 11.491, "27": 11.491}, "speed": "M"},
      {"moves": {"20": 7.5, "21": -22.5, "22": 12.99, "23": 12.99, "24": -7.5, "25": 22.5, "26": 12.99, "27": 12.99}, "speed": "M"},
      {"moves": {"20": 9.87, "21": -20.13, "22": 14.095, "23": 14.095, "24": -9.87, "25": 20.13, "26": 14.095, "27": 14.095}, "speed": "M"},
      {"moves": {"20": 12.395, "21": -17.605, "22": 14.772, "23": 14.772, "24": -12.395, "25": 17.605, "26": 14.772, "27": 14.772}, "speed": "M"},
      {"moves": {"20": 15.0, "21": -15.0, "22": 15.0, "23": 15.0, "24": -15.0, "25": 15.0, "26": 15.0, "27": 15.0}, "speed": "M"}
    ]
  }
}
```

#### 4. spider_turn_left

Complete sequence: 37 steps.

```json
{
  "robot_type": "spider",
  "movements": {
    "spider_turn_left": [
      {"moves": {"20": 15.0, "21": -15.0, "22": 15.0, "23": 15.0, "24": -15.0, "25": 15.0, "26": 15.0, "27": 15.0}, "speed": "M"},
      {"moves": {"20": 17.605, "21": -17.605, "22": 14.772, "23": 14.772, "24": -17.605, "25": 17.605, "26": 14.772, "27": 14.772}, "speed": "M"},
      {"moves": {"20": 20.13, "21": -20.13, "22": 14.095, "23": 14.095, "24": -20.13, "25": 20.13, "26": 14.095, "27": 14.095}, "speed": "M"},
      {"moves": {"20": 22.5, "21": -22.5, "22": 12.99, "23": 12.99, "24": -22.5, "25": 22.5, "26": 12.99, "27": 12.99}, "speed": "M"},
      {"moves": {"20": 24.642, "21": -24.642, "22": 11.491, "23": 11.491, "24": -24.642, "25": 24.642, "26": 11.491, "27": 11.491}, "speed": "M"},
      {"moves": {"20": 26.491, "21": -26.491, "22": 9.642, "23": 9.642, "24": -26.491, "25": 26.491, "26": 9.642, "27": 9.642}, "speed": "M"},
      {"moves": {"20": 27.99, "21": -27.99, "22": 7.5, "23": 7.5, "24": -27.99, "25": 27.99, "26": 7.5, "27": 7.5}, "speed": "M"},
      {"moves": {"20": 29.095, "21": -29.095, "22": 5.13, "23": 5.13, "24": -29.095, "25": 29.095, "26": 5.13, "27": 5.13}, "speed": "M"},
      {"moves": {"20": 29.772, "21": -29.772, "22": 2.605, "23": 2.605, "24": -29.772, "25": 29.772, "26": 2.605, "27": 2.605}, "speed": "M"},
      {"moves": {"20": 30.0, "21": -30.0, "22": 0.0, "23": 0.0, "24": -30.0, "25": 30.0, "26": 0.0, "27": 0.0}, "speed": "M"},
      {"moves": {"20": 29.772, "21": -29.772, "22": -2.605, "23": -2.605, "24": -29.772, "25": 29.772, "26": -2.605, "27": -2.605}, "speed": "M"},
      {"moves": {"20": 29.095, "21": -29.095, "22": -5.13, "23": -5.13, "24": -29.095, "25": 29.095, "26": -5.13, "27": -5.13}, "speed": "M"},
      {"moves": {"20": 27.99, "21": -27.99, "22": -7.5, "23": -7.5, "24": -27.99, "25": 27.99, "26": -7.5, "27": -7.5}, "speed": "M"},
      {"moves": {"20": 26.491, "21": -26.491, "22": -9.642, "23": -9.642, "24": -26.491, "25": 26.491, "26": -9.642, "27": -9.642}, "speed": "M"},
      {"moves": {"20": 24.642, "21": -24.642, "22": -11.491, "23": -11.491, "24": -24.642, "25": 24.642, "26": -11.491, "27": -11.491}, "speed": "M"},
      {"moves": {"20": 22.5, "21": -22.5, "22": -12.99, "23": -12.99, "24": -22.5, "25": 22.5, "26": -12.99, "27": -12.99}, "speed": "M"},
      {"moves": {"20": 20.13, "21": -20.13, "22": -14.095, "23": -14.095, "24": -20.13, "25": 20.13, "26": -14.095, "27": -14.095}, "speed": "M"},
      {"moves": {"20": 17.605, "21": -17.605, "22": -14.772, "23": -14.772, "24": -17.605, "25": 17.605, "26": -14.772, "27": -14.772}, "speed": "M"},
      {"moves": {"20": 15.0, "21": -15.0, "22": -15.0, "23": -15.0, "24": -15.0, "25": 15.0, "26": -15.0, "27": -15.0}, "speed": "M"},
      {"moves": {"20": 12.395, "21": -12.395, "22": -14.772, "23": -14.772, "24": -12.395, "25": 12.395, "26": -14.772, "27": -14.772}, "speed": "M"},
      {"moves": {"20": 9.87, "21": -9.87, "22": -14.095, "23": -14.095, "24": -9.87, "25": 9.87, "26": -14.095, "27": -14.095}, "speed": "M"},
      {"moves": {"20": 7.5, "21": -7.5, "22": -12.99, "23": -12.99, "24": -7.5, "25": 7.5, "26": -12.99, "27": -12.99}, "speed": "M"},
      {"moves": {"20": 5.358, "21": -5.358, "22": -11.491, "23": -11.491, "24": -5.358, "25": 5.358, "26": -11.491, "27": -11.491}, "speed": "M"},
      {"moves": {"20": 3.509, "21": -3.509, "22": -9.642, "23": -9.642, "24": -3.509, "25": 3.509, "26": -9.642, "27": -9.642}, "speed": "M"},
      {"moves": {"20": 2.01, "21": -2.01, "22": -7.5, "23": -7.5, "24": -2.01, "25": 2.01, "26": -7.5, "27": -7.5}, "speed": "M"},
      {"moves": {"20": 0.905, "21": -0.905, "22": -5.13, "23": -5.13, "24": -0.905, "25": 0.905, "26": -5.13, "27": -5.13}, "speed": "M"},
      {"moves": {"20": 0.228, "21": -0.228, "22": -2.605, "23": -2.605, "24": -0.228, "25": 0.228, "26": -2.605, "27": -2.605}, "speed": "M"},
      {"moves": {"20": 0.0, "21": 0.0, "22": 0.0, "23": 0.0, "24": 0.0, "25": 0.0, "26": 0.0, "27": 0.0}, "speed": "M"},
      {"moves": {"20": 0.228, "21": -0.228, "22": 2.605, "23": 2.605, "24": -0.228, "25": 0.228, "26": 2.605, "27": 2.605}, "speed": "M"},
      {"moves": {"20": 0.905, "21": -0.905, "22": 5.13, "23": 5.13, "24": -0.905, "25": 0.905, "26": 5.13, "27": 5.13}, "speed": "M"},
      {"moves": {"20": 2.01, "21": -2.01, "22": 7.5, "23": 7.5, "24": -2.01, "25": 2.01, "26": 7.5, "27": 7.5}, "speed": "M"},
      {"moves": {"20": 3.509, "21": -3.509, "22": 9.642, "23": 9.642, "24": -3.509, "25": 3.509, "26": 9.642, "27": 9.642}, "speed": "M"},
      {"moves": {"20": 5.358, "21": -5.358, "22": 11.491, "23": 11.491, "24": -5.358, "25": 5.358, "26": 11.491, "27": 11.491}, "speed": "M"},
      {"moves": {"20": 7.5, "21": -7.5, "22": 12.99, "23": 12.99, "24": -7.5, "25": 7.5, "26": 12.99, "27": 12.99}, "speed": "M"},
      {"moves": {"20": 9.87, "21": -9.87, "22": 14.095, "23": 14.095, "24": -9.87, "25": 9.87, "26": 14.095, "27": 14.095}, "speed": "M"},
      {"moves": {"20": 12.395, "21": -12.395, "22": 14.772, "23": 14.772, "24": -12.395, "25": 12.395, "26": 14.772, "27": 14.772}, "speed": "M"},
      {"moves": {"20": 15.0, "21": -15.0, "22": 15.0, "23": 15.0, "24": -15.0, "25": 15.0, "26": 15.0, "27": 15.0}, "speed": "M"}
    ]
  }
}
```

#### 5. spider_turn_right

Complete sequence: 37 steps.

```json
{
  "robot_type": "spider",
  "movements": {
    "spider_turn_right": [
      {"moves": {"20": 15.0, "21": -15.0, "22": 15.0, "23": 15.0, "24": -15.0, "25": 15.0, "26": 15.0, "27": 15.0}, "speed": "M"},
      {"moves": {"20": 12.395, "21": -12.395, "22": 14.772, "23": 14.772, "24": -12.395, "25": 12.395, "26": 14.772, "27": 14.772}, "speed": "M"},
      {"moves": {"20": 9.87, "21": -9.87, "22": 14.095, "23": 14.095, "24": -9.87, "25": 9.87, "26": 14.095, "27": 14.095}, "speed": "M"},
      {"moves": {"20": 7.5, "21": -7.5, "22": 12.99, "23": 12.99, "24": -7.5, "25": 7.5, "26": 12.99, "27": 12.99}, "speed": "M"},
      {"moves": {"20": 5.358, "21": -5.358, "22": 11.491, "23": 11.491, "24": -5.358, "25": 5.358, "26": 11.491, "27": 11.491}, "speed": "M"},
      {"moves": {"20": 3.509, "21": -3.509, "22": 9.642, "23": 9.642, "24": -3.509, "25": 3.509, "26": 9.642, "27": 9.642}, "speed": "M"},
      {"moves": {"20": 2.01, "21": -2.01, "22": 7.5, "23": 7.5, "24": -2.01, "25": 2.01, "26": 7.5, "27": 7.5}, "speed": "M"},
      {"moves": {"20": 0.905, "21": -0.905, "22": 5.13, "23": 5.13, "24": -0.905, "25": 0.905, "26": 5.13, "27": 5.13}, "speed": "M"},
      {"moves": {"20": 0.228, "21": -0.228, "22": 2.605, "23": 2.605, "24": -0.228, "25": 0.228, "26": 2.605, "27": 2.605}, "speed": "M"},
      {"moves": {"20": 0.0, "21": 0.0, "22": 0.0, "23": 0.0, "24": 0.0, "25": 0.0, "26": 0.0, "27": 0.0}, "speed": "M"},
      {"moves": {"20": 0.228, "21": -0.228, "22": -2.605, "23": -2.605, "24": -0.228, "25": 0.228, "26": -2.605, "27": -2.605}, "speed": "M"},
      {"moves": {"20": 0.905, "21": -0.905, "22": -5.13, "23": -5.13, "24": -0.905, "25": 0.905, "26": -5.13, "27": -5.13}, "speed": "M"},
      {"moves": {"20": 2.01, "21": -2.01, "22": -7.5, "23": -7.5, "24": -2.01, "25": 2.01, "26": -7.5, "27": -7.5}, "speed": "M"},
      {"moves": {"20": 3.509, "21": -3.509, "22": -9.642, "23": -9.642, "24": -3.509, "25": 3.509, "26": -9.642, "27": -9.642}, "speed": "M"},
      {"moves": {"20": 5.358, "21": -5.358, "22": -11.491, "23": -11.491, "24": -5.358, "25": 5.358, "26": -11.491, "27": -11.491}, "speed": "M"},
      {"moves": {"20": 7.5, "21": -7.5, "22": -12.99, "23": -12.99, "24": -7.5, "25": 7.5, "26": -12.99, "27": -12.99}, "speed": "M"},
      {"moves": {"20": 9.87, "21": -9.87, "22": -14.095, "23": -14.095, "24": -9.87, "25": 9.87, "26": -14.095, "27": -14.095}, "speed": "M"},
      {"moves": {"20": 12.395, "21": -12.395, "22": -14.772, "23": -14.772, "24": -12.395, "25": 12.395, "26": -14.772, "27": -14.772}, "speed": "M"},
      {"moves": {"20": 15.0, "21": -15.0, "22": -15.0, "23": -15.0, "24": -15.0, "25": 15.0, "26": -15.0, "27": -15.0}, "speed": "M"},
      {"moves": {"20": 17.605, "21": -17.605, "22": -14.772, "23": -14.772, "24": -17.605, "25": 17.605, "26": -14.772, "27": -14.772}, "speed": "M"},
      {"moves": {"20": 20.13, "21": -20.13, "22": -14.095, "23": -14.095, "24": -20.13, "25": 20.13, "26": -14.095, "27": -14.095}, "speed": "M"},
      {"moves": {"20": 22.5, "21": -22.5, "22": -12.99, "23": -12.99, "24": -22.5, "25": 22.5, "26": -12.99, "27": -12.99}, "speed": "M"},
      {"moves": {"20": 24.642, "21": -24.642, "22": -11.491, "23": -11.491, "24": -24.642, "25": 24.642, "26": -11.491, "27": -11.491}, "speed": "M"},
      {"moves": {"20": 26.491, "21": -26.491, "22": -9.642, "23": -9.642, "24": -26.491, "25": 26.491, "26": -9.642, "27": -9.642}, "speed": "M"},
      {"moves": {"20": 27.99, "21": -27.99, "22": -7.5, "23": -7.5, "24": -27.99, "25": 27.99, "26": -7.5, "27": -7.5}, "speed": "M"},
      {"moves": {"20": 29.095, "21": -29.095, "22": -5.13, "23": -5.13, "24": -29.095, "25": 29.095, "26": -5.13, "27": -5.13}, "speed": "M"},
      {"moves": {"20": 29.772, "21": -29.772, "22": -2.605, "23": -2.605, "24": -29.772, "25": 29.772, "26": -2.605, "27": -2.605}, "speed": "M"},
      {"moves": {"20": 30.0, "21": -30.0, "22": 0.0, "23": 0.0, "24": -30.0, "25": 30.0, "26": 0.0, "27": 0.0}, "speed": "M"},
      {"moves": {"20": 29.772, "21": -29.772, "22": 2.605, "23": 2.605, "24": -29.772, "25": 29.772, "26": 2.605, "27": 2.605}, "speed": "M"},
      {"moves": {"20": 29.095, "21": -29.095, "22": 5.13, "23": 5.13, "24": -29.095, "25": 29.095, "26": 5.13, "27": 5.13}, "speed": "M"},
      {"moves": {"20": 27.99, "21": -27.99, "22": 7.5, "23": 7.5, "24": -27.99, "25": 27.99, "26": 7.5, "27": 7.5}, "speed": "M"},
      {"moves": {"20": 26.491, "21": -26.491, "22": 9.642, "23": 9.642, "24": -26.491, "25": 26.491, "26": 9.642, "27": 9.642}, "speed": "M"},
      {"moves": {"20": 24.642, "21": -24.642, "22": 11.491, "23": 11.491, "24": -24.642, "25": 24.642, "26": 11.491, "27": 11.491}, "speed": "M"},
      {"moves": {"20": 22.5, "21": -22.5, "22": 12.99, "23": 12.99, "24": -22.5, "25": 22.5, "26": 12.99, "27": 12.99}, "speed": "M"},
      {"moves": {"20": 20.13, "21": -20.13, "22": 14.095, "23": 14.095, "24": -20.13, "25": 20.13, "26": 14.095, "27": 14.095}, "speed": "M"},
      {"moves": {"20": 17.605, "21": -17.605, "22": 14.772, "23": 14.772, "24": -17.605, "25": 17.605, "26": 14.772, "27": 14.772}, "speed": "M"},
      {"moves": {"20": 15.0, "21": -15.0, "22": 15.0, "23": 15.0, "24": -15.0, "25": 15.0, "26": 15.0, "27": 15.0}, "speed": "M"}
    ]
  }
}
```

#### 6. spider_dance

Complete sequence: 37 steps.

```json
{
  "robot_type": "spider",
  "movements": {
    "spider_dance": [
      {"moves": {"20": 30.0, "21": -30.0, "22": 0.0, "23": 40.0, "24": -30.0, "25": 30.0, "26": -40.0, "27": 0.0}, "speed": "M"},
      {"moves": {"20": 30.0, "21": -30.0, "22": -6.946, "23": 39.392, "24": -30.0, "25": 30.0, "26": -39.392, "27": 6.946}, "speed": "M"},
      {"moves": {"20": 30.0, "21": -30.0, "22": -13.681, "23": 37.588, "24": -30.0, "25": 30.0, "26": -37.588, "27": 13.681}, "speed": "M"},
      {"moves": {"20": 30.0, "21": -30.0, "22": -20.0, "23": 34.641, "24": -30.0, "25": 30.0, "26": -34.641, "27": 20.0}, "speed": "M"},
      {"moves": {"20": 30.0, "21": -30.0, "22": -25.712, "23": 30.642, "24": -30.0, "25": 30.0, "26": -30.642, "27": 25.712}, "speed": "M"},
      {"moves": {"20": 30.0, "21": -30.0, "22": -30.642, "23": 25.712, "24": -30.0, "25": 30.0, "26": -25.712, "27": 30.642}, "speed": "M"},
      {"moves": {"20": 30.0, "21": -30.0, "22": -34.641, "23": 20.0, "24": -30.0, "25": 30.0, "26": -20.0, "27": 34.641}, "speed": "M"},
      {"moves": {"20": 30.0, "21": -30.0, "22": -37.588, "23": 13.681, "24": -30.0, "25": 30.0, "26": -13.681, "27": 37.588}, "speed": "M"},
      {"moves": {"20": 30.0, "21": -30.0, "22": -39.392, "23": 6.946, "24": -30.0, "25": 30.0, "26": -6.946, "27": 39.392}, "speed": "M"},
      {"moves": {"20": 30.0, "21": -30.0, "22": -40.0, "23": 0.0, "24": -30.0, "25": 30.0, "26": 0.0, "27": 40.0}, "speed": "M"},
      {"moves": {"20": 30.0, "21": -30.0, "22": -39.392, "23": -6.946, "24": -30.0, "25": 30.0, "26": 6.946, "27": 39.392}, "speed": "M"},
      {"moves": {"20": 30.0, "21": -30.0, "22": -37.588, "23": -13.681, "24": -30.0, "25": 30.0, "26": 13.681, "27": 37.588}, "speed": "M"},
      {"moves": {"20": 30.0, "21": -30.0, "22": -34.641, "23": -20.0, "24": -30.0, "25": 30.0, "26": 20.0, "27": 34.641}, "speed": "M"},
      {"moves": {"20": 30.0, "21": -30.0, "22": -30.642, "23": -25.712, "24": -30.0, "25": 30.0, "26": 25.712, "27": 30.642}, "speed": "M"},
      {"moves": {"20": 30.0, "21": -30.0, "22": -25.712, "23": -30.642, "24": -30.0, "25": 30.0, "26": 30.642, "27": 25.712}, "speed": "M"},
      {"moves": {"20": 30.0, "21": -30.0, "22": -20.0, "23": -34.641, "24": -30.0, "25": 30.0, "26": 34.641, "27": 20.0}, "speed": "M"},
      {"moves": {"20": 30.0, "21": -30.0, "22": -13.681, "23": -37.588, "24": -30.0, "25": 30.0, "26": 37.588, "27": 13.681}, "speed": "M"},
      {"moves": {"20": 30.0, "21": -30.0, "22": -6.946, "23": -39.392, "24": -30.0, "25": 30.0, "26": 39.392, "27": 6.946}, "speed": "M"},
      {"moves": {"20": 30.0, "21": -30.0, "22": 0.0, "23": -40.0, "24": -30.0, "25": 30.0, "26": 40.0, "27": 0.0}, "speed": "M"},
      {"moves": {"20": 30.0, "21": -30.0, "22": 6.946, "23": -39.392, "24": -30.0, "25": 30.0, "26": 39.392, "27": -6.946}, "speed": "M"},
      {"moves": {"20": 30.0, "21": -30.0, "22": 13.681, "23": -37.588, "24": -30.0, "25": 30.0, "26": 37.588, "27": -13.681}, "speed": "M"},
      {"moves": {"20": 30.0, "21": -30.0, "22": 20.0, "23": -34.641, "24": -30.0, "25": 30.0, "26": 34.641, "27": -20.0}, "speed": "M"},
      {"moves": {"20": 30.0, "21": -30.0, "22": 25.712, "23": -30.642, "24": -30.0, "25": 30.0, "26": 30.642, "27": -25.712}, "speed": "M"},
      {"moves": {"20": 30.0, "21": -30.0, "22": 30.642, "23": -25.712, "24": -30.0, "25": 30.0, "26": 25.712, "27": -30.642}, "speed": "M"},
      {"moves": {"20": 30.0, "21": -30.0, "22": 34.641, "23": -20.0, "24": -30.0, "25": 30.0, "26": 20.0, "27": -34.641}, "speed": "M"},
      {"moves": {"20": 30.0, "21": -30.0, "22": 37.588, "23": -13.681, "24": -30.0, "25": 30.0, "26": 13.681, "27": -37.588}, "speed": "M"},
      {"moves": {"20": 30.0, "21": -30.0, "22": 39.392, "23": -6.946, "24": -30.0, "25": 30.0, "26": 6.946, "27": -39.392}, "speed": "M"},
      {"moves": {"20": 30.0, "21": -30.0, "22": 40.0, "23": 0.0, "24": -30.0, "25": 30.0, "26": 0.0, "27": -40.0}, "speed": "M"},
      {"moves": {"20": 30.0, "21": -30.0, "22": 39.392, "23": 6.946, "24": -30.0, "25": 30.0, "26": -6.946, "27": -39.392}, "speed": "M"},
      {"moves": {"20": 30.0, "21": -30.0, "22": 37.588, "23": 13.681, "24": -30.0, "25": 30.0, "26": -13.681, "27": -37.588}, "speed": "M"},
      {"moves": {"20": 30.0, "21": -30.0, "22": 34.641, "23": 20.0, "24": -30.0, "25": 30.0, "26": -20.0, "27": -34.641}, "speed": "M"},
      {"moves": {"20": 30.0, "21": -30.0, "22": 30.642, "23": 25.712, "24": -30.0, "25": 30.0, "26": -25.712, "27": -30.642}, "speed": "M"},
      {"moves": {"20": 30.0, "21": -30.0, "22": 25.712, "23": 30.642, "24": -30.0, "25": 30.0, "26": -30.642, "27": -25.712}, "speed": "M"},
      {"moves": {"20": 30.0, "21": -30.0, "22": 20.0, "23": 34.641, "24": -30.0, "25": 30.0, "26": -34.641, "27": -20.0}, "speed": "M"},
      {"moves": {"20": 30.0, "21": -30.0, "22": 13.681, "23": 37.588, "24": -30.0, "25": 30.0, "26": -37.588, "27": -13.681}, "speed": "M"},
      {"moves": {"20": 30.0, "21": -30.0, "22": 6.946, "23": 39.392, "24": -30.0, "25": 30.0, "26": -39.392, "27": -6.946}, "speed": "M"},
      {"moves": {"20": 30.0, "21": -30.0, "22": 0.0, "23": 40.0, "24": -30.0, "25": 30.0, "26": -40.0, "27": 0.0}, "speed": "M"}
    ]
  }
}
```

#### 7. spider_front_back

Complete sequence: 37 steps.

```json
{
  "robot_type": "spider",
  "movements": {
    "spider_front_back": [
      {"moves": {"20": 20.0, "21": -20.0, "22": -25.0, "23": 25.0, "24": -20.0, "25": 20.0, "26": 25.0, "27": -25.0}, "speed": "M"},
      {"moves": {"20": 14.791, "21": -14.791, "22": -24.62, "23": 24.62, "24": -25.209, "25": 25.209, "26": 24.62, "27": -24.62}, "speed": "M"},
      {"moves": {"20": 9.739, "21": -9.739, "22": -23.492, "23": 23.492, "24": -30.261, "25": 30.261, "26": 23.492, "27": -23.492}, "speed": "M"},
      {"moves": {"20": 5.0, "21": -5.0, "22": -21.651, "23": 21.651, "24": -35.0, "25": 35.0, "26": 21.651, "27": -21.651}, "speed": "M"},
      {"moves": {"20": 0.716, "21": -0.716, "22": -19.151, "23": 19.151, "24": -39.284, "25": 39.284, "26": 19.151, "27": -19.151}, "speed": "M"},
      {"moves": {"20": -2.981, "21": 2.981, "22": -16.07, "23": 16.07, "24": -42.981, "25": 42.981, "26": 16.07, "27": -16.07}, "speed": "M"},
      {"moves": {"20": -5.981, "21": 5.981, "22": -12.5, "23": 12.5, "24": -45.981, "25": 45.981, "26": 12.5, "27": -12.5}, "speed": "M"},
      {"moves": {"20": -8.191, "21": 8.191, "22": -8.551, "23": 8.551, "24": -48.191, "25": 48.191, "26": 8.551, "27": -8.551}, "speed": "M"},
      {"moves": {"20": -9.544, "21": 9.544, "22": -4.341, "23": 4.341, "24": -49.544, "25": 49.544, "26": 4.341, "27": -4.341}, "speed": "M"},
      {"moves": {"20": -10.0, "21": 10.0, "22": 0.0, "23": 0.0, "24": -50.0, "25": 50.0, "26": 0.0, "27": 0.0}, "speed": "M"},
      {"moves": {"20": -9.544, "21": 9.544, "22": 4.341, "23": -4.341, "24": -49.544, "25": 49.544, "26": -4.341, "27": 4.341}, "speed": "M"},
      {"moves": {"20": -8.191, "21": 8.191, "22": 8.551, "23": -8.551, "24": -48.191, "25": 48.191, "26": -8.551, "27": 8.551}, "speed": "M"},
      {"moves": {"20": -5.981, "21": 5.981, "22": 12.5, "23": -12.5, "24": -45.981, "25": 45.981, "26": -12.5, "27": 12.5}, "speed": "M"},
      {"moves": {"20": -2.981, "21": 2.981, "22": 16.07, "23": -16.07, "24": -42.981, "25": 42.981, "26": -16.07, "27": 16.07}, "speed": "M"},
      {"moves": {"20": 0.716, "21": -0.716, "22": 19.151, "23": -19.151, "24": -39.284, "25": 39.284, "26": -19.151, "27": 19.151}, "speed": "M"},
      {"moves": {"20": 5.0, "21": -5.0, "22": 21.651, "23": -21.651, "24": -35.0, "25": 35.0, "26": -21.651, "27": 21.651}, "speed": "M"},
      {"moves": {"20": 9.739, "21": -9.739, "22": 23.492, "23": -23.492, "24": -30.261, "25": 30.261, "26": -23.492, "27": 23.492}, "speed": "M"},
      {"moves": {"20": 14.791, "21": -14.791, "22": 24.62, "23": -24.62, "24": -25.209, "25": 25.209, "26": -24.62, "27": 24.62}, "speed": "M"},
      {"moves": {"20": 20.0, "21": -20.0, "22": 25.0, "23": -25.0, "24": -20.0, "25": 20.0, "26": -25.0, "27": 25.0}, "speed": "M"},
      {"moves": {"20": 25.209, "21": -25.209, "22": 24.62, "23": -24.62, "24": -14.791, "25": 14.791, "26": -24.62, "27": 24.62}, "speed": "M"},
      {"moves": {"20": 30.261, "21": -30.261, "22": 23.492, "23": -23.492, "24": -9.739, "25": 9.739, "26": -23.492, "27": 23.492}, "speed": "M"},
      {"moves": {"20": 35.0, "21": -35.0, "22": 21.651, "23": -21.651, "24": -5.0, "25": 5.0, "26": -21.651, "27": 21.651}, "speed": "M"},
      {"moves": {"20": 39.284, "21": -39.284, "22": 19.151, "23": -19.151, "24": -0.716, "25": 0.716, "26": -19.151, "27": 19.151}, "speed": "M"},
      {"moves": {"20": 42.981, "21": -42.981, "22": 16.07, "23": -16.07, "24": 2.981, "25": -2.981, "26": -16.07, "27": 16.07}, "speed": "M"},
      {"moves": {"20": 45.981, "21": -45.981, "22": 12.5, "23": -12.5, "24": 5.981, "25": -5.981, "26": -12.5, "27": 12.5}, "speed": "M"},
      {"moves": {"20": 48.191, "21": -48.191, "22": 8.551, "23": -8.551, "24": 8.191, "25": -8.191, "26": -8.551, "27": 8.551}, "speed": "M"},
      {"moves": {"20": 49.544, "21": -49.544, "22": 4.341, "23": -4.341, "24": 9.544, "25": -9.544, "26": -4.341, "27": 4.341}, "speed": "M"},
      {"moves": {"20": 50.0, "21": -50.0, "22": 0.0, "23": 0.0, "24": 10.0, "25": -10.0, "26": 0.0, "27": 0.0}, "speed": "M"},
      {"moves": {"20": 49.544, "21": -49.544, "22": -4.341, "23": 4.341, "24": 9.544, "25": -9.544, "26": 4.341, "27": -4.341}, "speed": "M"},
      {"moves": {"20": 48.191, "21": -48.191, "22": -8.551, "23": 8.551, "24": 8.191, "25": -8.191, "26": 8.551, "27": -8.551}, "speed": "M"},
      {"moves": {"20": 45.981, "21": -45.981, "22": -12.5, "23": 12.5, "24": 5.981, "25": -5.981, "26": 12.5, "27": -12.5}, "speed": "M"},
      {"moves": {"20": 42.981, "21": -42.981, "22": -16.07, "23": 16.07, "24": 2.981, "25": -2.981, "26": 16.07, "27": -16.07}, "speed": "M"},
      {"moves": {"20": 39.284, "21": -39.284, "22": -19.151, "23": 19.151, "24": -0.716, "25": 0.716, "26": 19.151, "27": -19.151}, "speed": "M"},
      {"moves": {"20": 35.0, "21": -35.0, "22": -21.651, "23": 21.651, "24": -5.0, "25": 5.0, "26": 21.651, "27": -21.651}, "speed": "M"},
      {"moves": {"20": 30.261, "21": -30.261, "22": -23.492, "23": 23.492, "24": -9.739, "25": 9.739, "26": 23.492, "27": -23.492}, "speed": "M"},
      {"moves": {"20": 25.209, "21": -25.209, "22": -24.62, "23": 24.62, "24": -14.791, "25": 14.791, "26": 24.62, "27": -24.62}, "speed": "M"},
      {"moves": {"20": 20.0, "21": -20.0, "22": -25.0, "23": 25.0, "24": -20.0, "25": 20.0, "26": 25.0, "27": -25.0}, "speed": "M"}
    ]
  }
}
```

#### 8. spider_up_down

Complete sequence: 37 steps.

```json
{
  "robot_type": "spider",
  "movements": {
    "spider_up_down": [
      {"moves": {"20": 20.0, "21": -20.0, "22": 35.0, "23": -35.0, "24": -20.0, "25": 20.0, "26": -35.0, "27": 35.0}, "speed": "M"},
      {"moves": {"20": 20.0, "21": -20.0, "22": 34.468, "23": -34.468, "24": -20.0, "25": 20.0, "26": -34.468, "27": 34.468}, "speed": "M"},
      {"moves": {"20": 20.0, "21": -20.0, "22": 32.889, "23": -32.889, "24": -20.0, "25": 20.0, "26": -32.889, "27": 32.889}, "speed": "M"},
      {"moves": {"20": 20.0, "21": -20.0, "22": 30.311, "23": -30.311, "24": -20.0, "25": 20.0, "26": -30.311, "27": 30.311}, "speed": "M"},
      {"moves": {"20": 20.0, "21": -20.0, "22": 26.812, "23": -26.812, "24": -20.0, "25": 20.0, "26": -26.812, "27": 26.812}, "speed": "M"},
      {"moves": {"20": 20.0, "21": -20.0, "22": 22.498, "23": -22.498, "24": -20.0, "25": 20.0, "26": -22.498, "27": 22.498}, "speed": "M"},
      {"moves": {"20": 20.0, "21": -20.0, "22": 17.5, "23": -17.5, "24": -20.0, "25": 20.0, "26": -17.5, "27": 17.5}, "speed": "M"},
      {"moves": {"20": 20.0, "21": -20.0, "22": 11.971, "23": -11.971, "24": -20.0, "25": 20.0, "26": -11.971, "27": 11.971}, "speed": "M"},
      {"moves": {"20": 20.0, "21": -20.0, "22": 6.078, "23": -6.078, "24": -20.0, "25": 20.0, "26": -6.078, "27": 6.078}, "speed": "M"},
      {"moves": {"20": 20.0, "21": -20.0, "22": 0.0, "23": 0.0, "24": -20.0, "25": 20.0, "26": 0.0, "27": 0.0}, "speed": "M"},
      {"moves": {"20": 20.0, "21": -20.0, "22": -6.078, "23": 6.078, "24": -20.0, "25": 20.0, "26": 6.078, "27": -6.078}, "speed": "M"},
      {"moves": {"20": 20.0, "21": -20.0, "22": -11.971, "23": 11.971, "24": -20.0, "25": 20.0, "26": 11.971, "27": -11.971}, "speed": "M"},
      {"moves": {"20": 20.0, "21": -20.0, "22": -17.5, "23": 17.5, "24": -20.0, "25": 20.0, "26": 17.5, "27": -17.5}, "speed": "M"},
      {"moves": {"20": 20.0, "21": -20.0, "22": -22.498, "23": 22.498, "24": -20.0, "25": 20.0, "26": 22.498, "27": -22.498}, "speed": "M"},
      {"moves": {"20": 20.0, "21": -20.0, "22": -26.812, "23": 26.812, "24": -20.0, "25": 20.0, "26": 26.812, "27": -26.812}, "speed": "M"},
      {"moves": {"20": 20.0, "21": -20.0, "22": -30.311, "23": 30.311, "24": -20.0, "25": 20.0, "26": 30.311, "27": -30.311}, "speed": "M"},
      {"moves": {"20": 20.0, "21": -20.0, "22": -32.889, "23": 32.889, "24": -20.0, "25": 20.0, "26": 32.889, "27": -32.889}, "speed": "M"},
      {"moves": {"20": 20.0, "21": -20.0, "22": -34.468, "23": 34.468, "24": -20.0, "25": 20.0, "26": 34.468, "27": -34.468}, "speed": "M"},
      {"moves": {"20": 20.0, "21": -20.0, "22": -35.0, "23": 35.0, "24": -20.0, "25": 20.0, "26": 35.0, "27": -35.0}, "speed": "M"},
      {"moves": {"20": 20.0, "21": -20.0, "22": -34.468, "23": 34.468, "24": -20.0, "25": 20.0, "26": 34.468, "27": -34.468}, "speed": "M"},
      {"moves": {"20": 20.0, "21": -20.0, "22": -32.889, "23": 32.889, "24": -20.0, "25": 20.0, "26": 32.889, "27": -32.889}, "speed": "M"},
      {"moves": {"20": 20.0, "21": -20.0, "22": -30.311, "23": 30.311, "24": -20.0, "25": 20.0, "26": 30.311, "27": -30.311}, "speed": "M"},
      {"moves": {"20": 20.0, "21": -20.0, "22": -26.812, "23": 26.812, "24": -20.0, "25": 20.0, "26": 26.812, "27": -26.812}, "speed": "M"},
      {"moves": {"20": 20.0, "21": -20.0, "22": -22.498, "23": 22.498, "24": -20.0, "25": 20.0, "26": 22.498, "27": -22.498}, "speed": "M"},
      {"moves": {"20": 20.0, "21": -20.0, "22": -17.5, "23": 17.5, "24": -20.0, "25": 20.0, "26": 17.5, "27": -17.5}, "speed": "M"},
      {"moves": {"20": 20.0, "21": -20.0, "22": -11.971, "23": 11.971, "24": -20.0, "25": 20.0, "26": 11.971, "27": -11.971}, "speed": "M"},
      {"moves": {"20": 20.0, "21": -20.0, "22": -6.078, "23": 6.078, "24": -20.0, "25": 20.0, "26": 6.078, "27": -6.078}, "speed": "M"},
      {"moves": {"20": 20.0, "21": -20.0, "22": 0.0, "23": 0.0, "24": -20.0, "25": 20.0, "26": 0.0, "27": 0.0}, "speed": "M"},
      {"moves": {"20": 20.0, "21": -20.0, "22": 6.078, "23": -6.078, "24": -20.0, "25": 20.0, "26": -6.078, "27": 6.078}, "speed": "M"},
      {"moves": {"20": 20.0, "21": -20.0, "22": 11.971, "23": -11.971, "24": -20.0, "25": 20.0, "26": -11.971, "27": 11.971}, "speed": "M"},
      {"moves": {"20": 20.0, "21": -20.0, "22": 17.5, "23": -17.5, "24": -20.0, "25": 20.0, "26": -17.5, "27": 17.5}, "speed": "M"},
      {"moves": {"20": 20.0, "21": -20.0, "22": 22.498, "23": -22.498, "24": -20.0, "25": 20.0, "26": -22.498, "27": 22.498}, "speed": "M"},
      {"moves": {"20": 20.0, "21": -20.0, "22": 26.812, "23": -26.812, "24": -20.0, "25": 20.0, "26": -26.812, "27": 26.812}, "speed": "M"},
      {"moves": {"20": 20.0, "21": -20.0, "22": 30.311, "23": -30.311, "24": -20.0, "25": 20.0, "26": -30.311, "27": 30.311}, "speed": "M"},
      {"moves": {"20": 20.0, "21": -20.0, "22": 32.889, "23": -32.889, "24": -20.0, "25": 20.0, "26": -32.889, "27": 32.889}, "speed": "M"},
      {"moves": {"20": 20.0, "21": -20.0, "22": 34.468, "23": -34.468, "24": -20.0, "25": 20.0, "26": -34.468, "27": 34.468}, "speed": "M"},
      {"moves": {"20": 20.0, "21": -20.0, "22": 35.0, "23": -35.0, "24": -20.0, "25": 20.0, "26": -35.0, "27": 35.0}, "speed": "M"}
    ]
  }
}
```

#### 9. spider_push_up

Complete sequence: 37 steps.

```json
{
  "robot_type": "spider",
  "movements": {
    "spider_push_up": [
      {"moves": {"20": 65.0, "21": -65.0, "22": 0.0, "23": 0.0, "24": 0.0, "25": 0.0, "26": 0.0, "27": 0.0}, "speed": "M"},
      {"moves": {"20": 65.0, "21": -65.0, "22": 0.0, "23": 0.0, "24": 0.0, "25": 0.0, "26": -6.946, "27": 6.946}, "speed": "M"},
      {"moves": {"20": 65.0, "21": -65.0, "22": 0.0, "23": 0.0, "24": 0.0, "25": 0.0, "26": -13.681, "27": 13.681}, "speed": "M"},
      {"moves": {"20": 65.0, "21": -65.0, "22": 0.0, "23": 0.0, "24": 0.0, "25": 0.0, "26": -20.0, "27": 20.0}, "speed": "M"},
      {"moves": {"20": 65.0, "21": -65.0, "22": 0.0, "23": 0.0, "24": 0.0, "25": 0.0, "26": -25.712, "27": 25.712}, "speed": "M"},
      {"moves": {"20": 65.0, "21": -65.0, "22": 0.0, "23": 0.0, "24": 0.0, "25": 0.0, "26": -30.642, "27": 30.642}, "speed": "M"},
      {"moves": {"20": 65.0, "21": -65.0, "22": 0.0, "23": 0.0, "24": 0.0, "25": 0.0, "26": -34.641, "27": 34.641}, "speed": "M"},
      {"moves": {"20": 65.0, "21": -65.0, "22": 0.0, "23": 0.0, "24": 0.0, "25": 0.0, "26": -37.588, "27": 37.588}, "speed": "M"},
      {"moves": {"20": 65.0, "21": -65.0, "22": 0.0, "23": 0.0, "24": 0.0, "25": 0.0, "26": -39.392, "27": 39.392}, "speed": "M"},
      {"moves": {"20": 65.0, "21": -65.0, "22": 0.0, "23": 0.0, "24": 0.0, "25": 0.0, "26": -40.0, "27": 40.0}, "speed": "M"},
      {"moves": {"20": 65.0, "21": -65.0, "22": 0.0, "23": 0.0, "24": 0.0, "25": 0.0, "26": -39.392, "27": 39.392}, "speed": "M"},
      {"moves": {"20": 65.0, "21": -65.0, "22": 0.0, "23": 0.0, "24": 0.0, "25": 0.0, "26": -37.588, "27": 37.588}, "speed": "M"},
      {"moves": {"20": 65.0, "21": -65.0, "22": 0.0, "23": 0.0, "24": 0.0, "25": 0.0, "26": -34.641, "27": 34.641}, "speed": "M"},
      {"moves": {"20": 65.0, "21": -65.0, "22": 0.0, "23": 0.0, "24": 0.0, "25": 0.0, "26": -30.642, "27": 30.642}, "speed": "M"},
      {"moves": {"20": 65.0, "21": -65.0, "22": 0.0, "23": 0.0, "24": 0.0, "25": 0.0, "26": -25.712, "27": 25.712}, "speed": "M"},
      {"moves": {"20": 65.0, "21": -65.0, "22": 0.0, "23": 0.0, "24": 0.0, "25": 0.0, "26": -20.0, "27": 20.0}, "speed": "M"},
      {"moves": {"20": 65.0, "21": -65.0, "22": 0.0, "23": 0.0, "24": 0.0, "25": 0.0, "26": -13.681, "27": 13.681}, "speed": "M"},
      {"moves": {"20": 65.0, "21": -65.0, "22": 0.0, "23": 0.0, "24": 0.0, "25": 0.0, "26": -6.946, "27": 6.946}, "speed": "M"},
      {"moves": {"20": 65.0, "21": -65.0, "22": 0.0, "23": 0.0, "24": 0.0, "25": 0.0, "26": 0.0, "27": 0.0}, "speed": "M"},
      {"moves": {"20": 65.0, "21": -65.0, "22": 0.0, "23": 0.0, "24": 0.0, "25": 0.0, "26": 6.946, "27": -6.946}, "speed": "M"},
      {"moves": {"20": 65.0, "21": -65.0, "22": 0.0, "23": 0.0, "24": 0.0, "25": 0.0, "26": 13.681, "27": -13.681}, "speed": "M"},
      {"moves": {"20": 65.0, "21": -65.0, "22": 0.0, "23": 0.0, "24": 0.0, "25": 0.0, "26": 20.0, "27": -20.0}, "speed": "M"},
      {"moves": {"20": 65.0, "21": -65.0, "22": 0.0, "23": 0.0, "24": 0.0, "25": 0.0, "26": 25.712, "27": -25.712}, "speed": "M"},
      {"moves": {"20": 65.0, "21": -65.0, "22": 0.0, "23": 0.0, "24": 0.0, "25": 0.0, "26": 30.642, "27": -30.642}, "speed": "M"},
      {"moves": {"20": 65.0, "21": -65.0, "22": 0.0, "23": 0.0, "24": 0.0, "25": 0.0, "26": 34.641, "27": -34.641}, "speed": "M"},
      {"moves": {"20": 65.0, "21": -65.0, "22": 0.0, "23": 0.0, "24": 0.0, "25": 0.0, "26": 37.588, "27": -37.588}, "speed": "M"},
      {"moves": {"20": 65.0, "21": -65.0, "22": 0.0, "23": 0.0, "24": 0.0, "25": 0.0, "26": 39.392, "27": -39.392}, "speed": "M"},
      {"moves": {"20": 65.0, "21": -65.0, "22": 0.0, "23": 0.0, "24": 0.0, "25": 0.0, "26": 40.0, "27": -40.0}, "speed": "M"},
      {"moves": {"20": 65.0, "21": -65.0, "22": 0.0, "23": 0.0, "24": 0.0, "25": 0.0, "26": 39.392, "27": -39.392}, "speed": "M"},
      {"moves": {"20": 65.0, "21": -65.0, "22": 0.0, "23": 0.0, "24": 0.0, "25": 0.0, "26": 37.588, "27": -37.588}, "speed": "M"},
      {"moves": {"20": 65.0, "21": -65.0, "22": 0.0, "23": 0.0, "24": 0.0, "25": 0.0, "26": 34.641, "27": -34.641}, "speed": "M"},
      {"moves": {"20": 65.0, "21": -65.0, "22": 0.0, "23": 0.0, "24": 0.0, "25": 0.0, "26": 30.642, "27": -30.642}, "speed": "M"},
      {"moves": {"20": 65.0, "21": -65.0, "22": 0.0, "23": 0.0, "24": 0.0, "25": 0.0, "26": 25.712, "27": -25.712}, "speed": "M"},
      {"moves": {"20": 65.0, "21": -65.0, "22": 0.0, "23": 0.0, "24": 0.0, "25": 0.0, "26": 20.0, "27": -20.0}, "speed": "M"},
      {"moves": {"20": 65.0, "21": -65.0, "22": 0.0, "23": 0.0, "24": 0.0, "25": 0.0, "26": 13.681, "27": -13.681}, "speed": "M"},
      {"moves": {"20": 65.0, "21": -65.0, "22": 0.0, "23": 0.0, "24": 0.0, "25": 0.0, "26": 6.946, "27": -6.946}, "speed": "M"},
      {"moves": {"20": 65.0, "21": -65.0, "22": 0.0, "23": 0.0, "24": 0.0, "25": 0.0, "26": 0.0, "27": 0.0}, "speed": "M"}
    ]
  }
}
```

#### 10. spider_wave_hand

Complete sequence: 37 steps.

```json
{
  "robot_type": "spider",
  "movements": {
    "spider_wave_hand": [
      {"moves": {"20": 85.0, "21": -65.0, "22": 0.0, "23": 0.0, "24": 0.0, "25": 0.0, "26": -30.0, "27": -60.0}, "speed": "M"},
      {"moves": {"20": 85.0, "21": -65.0, "22": 0.0, "23": 0.0, "24": 0.0, "25": 0.0, "26": -30.0, "27": -63.473}, "speed": "M"},
      {"moves": {"20": 85.0, "21": -65.0, "22": 0.0, "23": 0.0, "24": 0.0, "25": 0.0, "26": -30.0, "27": -66.84}, "speed": "M"},
      {"moves": {"20": 85.0, "21": -65.0, "22": 0.0, "23": 0.0, "24": 0.0, "25": 0.0, "26": -30.0, "27": -70.0}, "speed": "M"},
      {"moves": {"20": 85.0, "21": -65.0, "22": 0.0, "23": 0.0, "24": 0.0, "25": 0.0, "26": -30.0, "27": -72.856}, "speed": "M"},
      {"moves": {"20": 85.0, "21": -65.0, "22": 0.0, "23": 0.0, "24": 0.0, "25": 0.0, "26": -30.0, "27": -75.321}, "speed": "M"},
      {"moves": {"20": 85.0, "21": -65.0, "22": 0.0, "23": 0.0, "24": 0.0, "25": 0.0, "26": -30.0, "27": -77.321}, "speed": "M"},
      {"moves": {"20": 85.0, "21": -65.0, "22": 0.0, "23": 0.0, "24": 0.0, "25": 0.0, "26": -30.0, "27": -78.794}, "speed": "M"},
      {"moves": {"20": 85.0, "21": -65.0, "22": 0.0, "23": 0.0, "24": 0.0, "25": 0.0, "26": -30.0, "27": -79.696}, "speed": "M"},
      {"moves": {"20": 85.0, "21": -65.0, "22": 0.0, "23": 0.0, "24": 0.0, "25": 0.0, "26": -30.0, "27": -80.0}, "speed": "M"},
      {"moves": {"20": 85.0, "21": -65.0, "22": 0.0, "23": 0.0, "24": 0.0, "25": 0.0, "26": -30.0, "27": -79.696}, "speed": "M"},
      {"moves": {"20": 85.0, "21": -65.0, "22": 0.0, "23": 0.0, "24": 0.0, "25": 0.0, "26": -30.0, "27": -78.794}, "speed": "M"},
      {"moves": {"20": 85.0, "21": -65.0, "22": 0.0, "23": 0.0, "24": 0.0, "25": 0.0, "26": -30.0, "27": -77.321}, "speed": "M"},
      {"moves": {"20": 85.0, "21": -65.0, "22": 0.0, "23": 0.0, "24": 0.0, "25": 0.0, "26": -30.0, "27": -75.321}, "speed": "M"},
      {"moves": {"20": 85.0, "21": -65.0, "22": 0.0, "23": 0.0, "24": 0.0, "25": 0.0, "26": -30.0, "27": -72.856}, "speed": "M"},
      {"moves": {"20": 85.0, "21": -65.0, "22": 0.0, "23": 0.0, "24": 0.0, "25": 0.0, "26": -30.0, "27": -70.0}, "speed": "M"},
      {"moves": {"20": 85.0, "21": -65.0, "22": 0.0, "23": 0.0, "24": 0.0, "25": 0.0, "26": -30.0, "27": -66.84}, "speed": "M"},
      {"moves": {"20": 85.0, "21": -65.0, "22": 0.0, "23": 0.0, "24": 0.0, "25": 0.0, "26": -30.0, "27": -63.473}, "speed": "M"},
      {"moves": {"20": 85.0, "21": -65.0, "22": 0.0, "23": 0.0, "24": 0.0, "25": 0.0, "26": -30.0, "27": -60.0}, "speed": "M"},
      {"moves": {"20": 85.0, "21": -65.0, "22": 0.0, "23": 0.0, "24": 0.0, "25": 0.0, "26": -30.0, "27": -56.527}, "speed": "M"},
      {"moves": {"20": 85.0, "21": -65.0, "22": 0.0, "23": 0.0, "24": 0.0, "25": 0.0, "26": -30.0, "27": -53.16}, "speed": "M"},
      {"moves": {"20": 85.0, "21": -65.0, "22": 0.0, "23": 0.0, "24": 0.0, "25": 0.0, "26": -30.0, "27": -50.0}, "speed": "M"},
      {"moves": {"20": 85.0, "21": -65.0, "22": 0.0, "23": 0.0, "24": 0.0, "25": 0.0, "26": -30.0, "27": -47.144}, "speed": "M"},
      {"moves": {"20": 85.0, "21": -65.0, "22": 0.0, "23": 0.0, "24": 0.0, "25": 0.0, "26": -30.0, "27": -44.679}, "speed": "M"},
      {"moves": {"20": 85.0, "21": -65.0, "22": 0.0, "23": 0.0, "24": 0.0, "25": 0.0, "26": -30.0, "27": -42.679}, "speed": "M"},
      {"moves": {"20": 85.0, "21": -65.0, "22": 0.0, "23": 0.0, "24": 0.0, "25": 0.0, "26": -30.0, "27": -41.206}, "speed": "M"},
      {"moves": {"20": 85.0, "21": -65.0, "22": 0.0, "23": 0.0, "24": 0.0, "25": 0.0, "26": -30.0, "27": -40.304}, "speed": "M"},
      {"moves": {"20": 85.0, "21": -65.0, "22": 0.0, "23": 0.0, "24": 0.0, "25": 0.0, "26": -30.0, "27": -40.0}, "speed": "M"},
      {"moves": {"20": 85.0, "21": -65.0, "22": 0.0, "23": 0.0, "24": 0.0, "25": 0.0, "26": -30.0, "27": -40.304}, "speed": "M"},
      {"moves": {"20": 85.0, "21": -65.0, "22": 0.0, "23": 0.0, "24": 0.0, "25": 0.0, "26": -30.0, "27": -41.206}, "speed": "M"},
      {"moves": {"20": 85.0, "21": -65.0, "22": 0.0, "23": 0.0, "24": 0.0, "25": 0.0, "26": -30.0, "27": -42.679}, "speed": "M"},
      {"moves": {"20": 85.0, "21": -65.0, "22": 0.0, "23": 0.0, "24": 0.0, "25": 0.0, "26": -30.0, "27": -44.679}, "speed": "M"},
      {"moves": {"20": 85.0, "21": -65.0, "22": 0.0, "23": 0.0, "24": 0.0, "25": 0.0, "26": -30.0, "27": -47.144}, "speed": "M"},
      {"moves": {"20": 85.0, "21": -65.0, "22": 0.0, "23": 0.0, "24": 0.0, "25": 0.0, "26": -30.0, "27": -50.0}, "speed": "M"},
      {"moves": {"20": 85.0, "21": -65.0, "22": 0.0, "23": 0.0, "24": 0.0, "25": 0.0, "26": -30.0, "27": -53.16}, "speed": "M"},
      {"moves": {"20": 85.0, "21": -65.0, "22": 0.0, "23": 0.0, "24": 0.0, "25": 0.0, "26": -30.0, "27": -56.527}, "speed": "M"},
      {"moves": {"20": 85.0, "21": -65.0, "22": 0.0, "23": 0.0, "24": 0.0, "25": 0.0, "26": -30.0, "27": -60.0}, "speed": "M"}
    ]
  }
}
```

#### 11. spider_hide

Complete sequence: 1 step.

```json
{
  "robot_type": "spider",
  "movements": {
    "spider_hide": [
      {"moves": {"20": 0.0, "21": 0.0, "22": -80.0, "23": 80.0, "24": 0.0, "25": 0.0, "26": 80.0, "27": -80.0}, "speed": "M"}
    ]
  }
}
```

#### 12. spider_moonwalk_left

Complete sequence: 37 steps.

```json
{
  "robot_type": "spider",
  "movements": {
    "spider_moonwalk_left": [
      {"moves": {"20": 0.0, "21": 0.0, "22": -42.286, "23": 0.0, "24": 0.0, "25": 0.0, "26": 38.971, "27": 0.0}, "speed": "M"},
      {"moves": {"20": 0.0, "21": 0.0, "22": -38.971, "23": -7.814, "24": 0.0, "25": 0.0, "26": 34.472, "27": 7.814}, "speed": "M"},
      {"moves": {"20": 0.0, "21": 0.0, "22": -34.472, "23": -15.391, "24": 0.0, "25": 0.0, "26": 28.925, "27": 15.391}, "speed": "M"},
      {"moves": {"20": 0.0, "21": 0.0, "22": -28.925, "23": -22.5, "24": 0.0, "25": 0.0, "26": 22.5, "27": 22.5}, "speed": "M"},
      {"moves": {"20": 0.0, "21": 0.0, "22": -22.5, "23": -28.925, "24": 0.0, "25": 0.0, "26": 15.391, "27": 28.925}, "speed": "M"},
      {"moves": {"20": 0.0, "21": 0.0, "22": -15.391, "23": -34.472, "24": 0.0, "25": 0.0, "26": 7.814, "27": 34.472}, "speed": "M"},
      {"moves": {"20": 0.0, "21": 0.0, "22": -7.814, "23": -38.971, "24": 0.0, "25": 0.0, "26": 0.0, "27": 38.971}, "speed": "M"},
      {"moves": {"20": 0.0, "21": 0.0, "22": 0.0, "23": -42.286, "24": 0.0, "25": 0.0, "26": -7.814, "27": 42.286}, "speed": "M"},
      {"moves": {"20": 0.0, "21": 0.0, "22": 7.814, "23": -44.316, "24": 0.0, "25": 0.0, "26": -15.391, "27": 44.316}, "speed": "M"},
      {"moves": {"20": 0.0, "21": 0.0, "22": 15.391, "23": -45.0, "24": 0.0, "25": 0.0, "26": -22.5, "27": 45.0}, "speed": "M"},
      {"moves": {"20": 0.0, "21": 0.0, "22": 22.5, "23": -44.316, "24": 0.0, "25": 0.0, "26": -28.925, "27": 44.316}, "speed": "M"},
      {"moves": {"20": 0.0, "21": 0.0, "22": 28.925, "23": -42.286, "24": 0.0, "25": 0.0, "26": -34.472, "27": 42.286}, "speed": "M"},
      {"moves": {"20": 0.0, "21": 0.0, "22": 34.472, "23": -38.971, "24": 0.0, "25": 0.0, "26": -38.971, "27": 38.971}, "speed": "M"},
      {"moves": {"20": 0.0, "21": 0.0, "22": 38.971, "23": -34.472, "24": 0.0, "25": 0.0, "26": -42.286, "27": 34.472}, "speed": "M"},
      {"moves": {"20": 0.0, "21": 0.0, "22": 42.286, "23": -28.925, "24": 0.0, "25": 0.0, "26": -44.316, "27": 28.925}, "speed": "M"},
      {"moves": {"20": 0.0, "21": 0.0, "22": 44.316, "23": -22.5, "24": 0.0, "25": 0.0, "26": -45.0, "27": 22.5}, "speed": "M"},
      {"moves": {"20": 0.0, "21": 0.0, "22": 45.0, "23": -15.391, "24": 0.0, "25": 0.0, "26": -44.316, "27": 15.391}, "speed": "M"},
      {"moves": {"20": 0.0, "21": 0.0, "22": 44.316, "23": -7.814, "24": 0.0, "25": 0.0, "26": -42.286, "27": 7.814}, "speed": "M"},
      {"moves": {"20": 0.0, "21": 0.0, "22": 42.286, "23": 0.0, "24": 0.0, "25": 0.0, "26": -38.971, "27": 0.0}, "speed": "M"},
      {"moves": {"20": 0.0, "21": 0.0, "22": 38.971, "23": 7.814, "24": 0.0, "25": 0.0, "26": -34.472, "27": -7.814}, "speed": "M"},
      {"moves": {"20": 0.0, "21": 0.0, "22": 34.472, "23": 15.391, "24": 0.0, "25": 0.0, "26": -28.925, "27": -15.391}, "speed": "M"},
      {"moves": {"20": 0.0, "21": 0.0, "22": 28.925, "23": 22.5, "24": 0.0, "25": 0.0, "26": -22.5, "27": -22.5}, "speed": "M"},
      {"moves": {"20": 0.0, "21": 0.0, "22": 22.5, "23": 28.925, "24": 0.0, "25": 0.0, "26": -15.391, "27": -28.925}, "speed": "M"},
      {"moves": {"20": 0.0, "21": 0.0, "22": 15.391, "23": 34.472, "24": 0.0, "25": 0.0, "26": -7.814, "27": -34.472}, "speed": "M"},
      {"moves": {"20": 0.0, "21": 0.0, "22": 7.814, "23": 38.971, "24": 0.0, "25": 0.0, "26": 0.0, "27": -38.971}, "speed": "M"},
      {"moves": {"20": 0.0, "21": 0.0, "22": 0.0, "23": 42.286, "24": 0.0, "25": 0.0, "26": 7.814, "27": -42.286}, "speed": "M"},
      {"moves": {"20": 0.0, "21": 0.0, "22": -7.814, "23": 44.316, "24": 0.0, "25": 0.0, "26": 15.391, "27": -44.316}, "speed": "M"},
      {"moves": {"20": 0.0, "21": 0.0, "22": -15.391, "23": 45.0, "24": 0.0, "25": 0.0, "26": 22.5, "27": -45.0}, "speed": "M"},
      {"moves": {"20": 0.0, "21": 0.0, "22": -22.5, "23": 44.316, "24": 0.0, "25": 0.0, "26": 28.925, "27": -44.316}, "speed": "M"},
      {"moves": {"20": 0.0, "21": 0.0, "22": -28.925, "23": 42.286, "24": 0.0, "25": 0.0, "26": 34.472, "27": -42.286}, "speed": "M"},
      {"moves": {"20": 0.0, "21": 0.0, "22": -34.472, "23": 38.971, "24": 0.0, "25": 0.0, "26": 38.971, "27": -38.971}, "speed": "M"},
      {"moves": {"20": 0.0, "21": 0.0, "22": -38.971, "23": 34.472, "24": 0.0, "25": 0.0, "26": 42.286, "27": -34.472}, "speed": "M"},
      {"moves": {"20": 0.0, "21": 0.0, "22": -42.286, "23": 28.925, "24": 0.0, "25": 0.0, "26": 44.316, "27": -28.925}, "speed": "M"},
      {"moves": {"20": 0.0, "21": 0.0, "22": -44.316, "23": 22.5, "24": 0.0, "25": 0.0, "26": 45.0, "27": -22.5}, "speed": "M"},
      {"moves": {"20": 0.0, "21": 0.0, "22": -45.0, "23": 15.391, "24": 0.0, "25": 0.0, "26": 44.316, "27": -15.391}, "speed": "M"},
      {"moves": {"20": 0.0, "21": 0.0, "22": -44.316, "23": 7.814, "24": 0.0, "25": 0.0, "26": 42.286, "27": -7.814}, "speed": "M"},
      {"moves": {"20": 0.0, "21": 0.0, "22": -42.286, "23": 0.0, "24": 0.0, "25": 0.0, "26": 38.971, "27": 0.0}, "speed": "M"}
    ]
  }
}
```

#### 13. spider_omni_true

Complete sequence: 37 steps.

```json
{
  "robot_type": "spider",
  "movements": {
    "spider_omni_true": [
      {"moves": {"20": -3.0, "21": 3.0, "22": -8.0, "23": 38.0, "24": -33.0, "25": 33.0, "26": 38.0, "27": -8.0}, "speed": "M"},
      {"moves": {"20": -5.605, "21": 0.395, "22": -8.228, "23": 37.772, "24": -30.395, "25": 35.605, "26": 37.772, "27": -8.228}, "speed": "M"},
      {"moves": {"20": -8.13, "21": -2.13, "22": -8.905, "23": 37.095, "24": -27.87, "25": 38.13, "26": 37.095, "27": -8.905}, "speed": "M"},
      {"moves": {"20": -10.5, "21": -4.5, "22": -10.01, "23": 35.99, "24": -25.5, "25": 40.5, "26": 35.99, "27": -10.01}, "speed": "M"},
      {"moves": {"20": -12.642, "21": -6.642, "22": -11.509, "23": 34.491, "24": -23.358, "25": 42.642, "26": 34.491, "27": -11.509}, "speed": "M"},
      {"moves": {"20": -14.491, "21": -8.491, "22": -13.358, "23": 32.642, "24": -21.509, "25": 44.491, "26": 32.642, "27": -13.358}, "speed": "M"},
      {"moves": {"20": -15.99, "21": -9.99, "22": -15.5, "23": 30.5, "24": -20.01, "25": 45.99, "26": 30.5, "27": -15.5}, "speed": "M"},
      {"moves": {"20": -17.095, "21": -11.095, "22": -17.87, "23": 28.13, "24": -18.905, "25": 47.095, "26": 28.13, "27": -17.87}, "speed": "M"},
      {"moves": {"20": -17.772, "21": -11.772, "22": -20.395, "23": 25.605, "24": -18.228, "25": 47.772, "26": 25.605, "27": -20.395}, "speed": "M"},
      {"moves": {"20": -18.0, "21": -12.0, "22": -23.0, "23": 23.0, "24": -18.0, "25": 48.0, "26": 23.0, "27": -23.0}, "speed": "M"},
      {"moves": {"20": -17.772, "21": -11.772, "22": -25.605, "23": 20.395, "24": -18.228, "25": 47.772, "26": 20.395, "27": -25.605}, "speed": "M"},
      {"moves": {"20": -17.095, "21": -11.095, "22": -28.13, "23": 17.87, "24": -18.905, "25": 47.095, "26": 17.87, "27": -28.13}, "speed": "M"},
      {"moves": {"20": -15.99, "21": -9.99, "22": -30.5, "23": 15.5, "24": -20.01, "25": 45.99, "26": 15.5, "27": -30.5}, "speed": "M"},
      {"moves": {"20": -14.491, "21": -8.491, "22": -32.642, "23": 13.358, "24": -21.509, "25": 44.491, "26": 13.358, "27": -32.642}, "speed": "M"},
      {"moves": {"20": -12.642, "21": -6.642, "22": -34.491, "23": 11.509, "24": -23.358, "25": 42.642, "26": 11.509, "27": -34.491}, "speed": "M"},
      {"moves": {"20": -10.5, "21": -4.5, "22": -35.99, "23": 10.01, "24": -25.5, "25": 40.5, "26": 10.01, "27": -35.99}, "speed": "M"},
      {"moves": {"20": -8.13, "21": -2.13, "22": -37.095, "23": 8.905, "24": -27.87, "25": 38.13, "26": 8.905, "27": -37.095}, "speed": "M"},
      {"moves": {"20": -5.605, "21": 0.395, "22": -37.772, "23": 8.228, "24": -30.395, "25": 35.605, "26": 8.228, "27": -37.772}, "speed": "M"},
      {"moves": {"20": -3.0, "21": 3.0, "22": -38.0, "23": 8.0, "24": -33.0, "25": 33.0, "26": 8.0, "27": -38.0}, "speed": "M"},
      {"moves": {"20": -0.395, "21": 5.605, "22": -37.772, "23": 8.228, "24": -35.605, "25": 30.395, "26": 8.228, "27": -37.772}, "speed": "M"},
      {"moves": {"20": 2.13, "21": 8.13, "22": -37.095, "23": 8.905, "24": -38.13, "25": 27.87, "26": 8.905, "27": -37.095}, "speed": "M"},
      {"moves": {"20": 4.5, "21": 10.5, "22": -35.99, "23": 10.01, "24": -40.5, "25": 25.5, "26": 10.01, "27": -35.99}, "speed": "M"},
      {"moves": {"20": 6.642, "21": 12.642, "22": -34.491, "23": 11.509, "24": -42.642, "25": 23.358, "26": 11.509, "27": -34.491}, "speed": "M"},
      {"moves": {"20": 8.491, "21": 14.491, "22": -32.642, "23": 13.358, "24": -44.491, "25": 21.509, "26": 13.358, "27": -32.642}, "speed": "M"},
      {"moves": {"20": 9.99, "21": 15.99, "22": -30.5, "23": 15.5, "24": -45.99, "25": 20.01, "26": 15.5, "27": -30.5}, "speed": "M"},
      {"moves": {"20": 11.095, "21": 17.095, "22": -28.13, "23": 17.87, "24": -47.095, "25": 18.905, "26": 17.87, "27": -28.13}, "speed": "M"},
      {"moves": {"20": 11.772, "21": 17.772, "22": -25.605, "23": 20.395, "24": -47.772, "25": 18.228, "26": 20.395, "27": -25.605}, "speed": "M"},
      {"moves": {"20": 12.0, "21": 18.0, "22": -23.0, "23": 23.0, "24": -48.0, "25": 18.0, "26": 23.0, "27": -23.0}, "speed": "M"},
      {"moves": {"20": 11.772, "21": 17.772, "22": -20.395, "23": 25.605, "24": -47.772, "25": 18.228, "26": 25.605, "27": -20.395}, "speed": "M"},
      {"moves": {"20": 11.095, "21": 17.095, "22": -17.87, "23": 28.13, "24": -47.095, "25": 18.905, "26": 28.13, "27": -17.87}, "speed": "M"},
      {"moves": {"20": 9.99, "21": 15.99, "22": -15.5, "23": 30.5, "24": -45.99, "25": 20.01, "26": 30.5, "27": -15.5}, "speed": "M"},
      {"moves": {"20": 8.491, "21": 14.491, "22": -13.358, "23": 32.642, "24": -44.491, "25": 21.509, "26": 32.642, "27": -13.358}, "speed": "M"},
      {"moves": {"20": 6.642, "21": 12.642, "22": -11.509, "23": 34.491, "24": -42.642, "25": 23.358, "26": 34.491, "27": -11.509}, "speed": "M"},
      {"moves": {"20": 4.5, "21": 10.5, "22": -10.01, "23": 35.99, "24": -40.5, "25": 25.5, "26": 35.99, "27": -10.01}, "speed": "M"},
      {"moves": {"20": 2.13, "21": 8.13, "22": -8.905, "23": 37.095, "24": -38.13, "25": 27.87, "26": 37.095, "27": -8.905}, "speed": "M"},
      {"moves": {"20": -0.395, "21": 5.605, "22": -8.228, "23": 37.772, "24": -35.605, "25": 30.395, "26": 37.772, "27": -8.228}, "speed": "M"},
      {"moves": {"20": -3.0, "21": 3.0, "22": -8.0, "23": 38.0, "24": -33.0, "25": 33.0, "26": 38.0, "27": -8.0}, "speed": "M"}
    ]
  }
}
```

#### 14. spider_omni_false

Complete sequence: 37 steps.

```json
{
  "robot_type": "spider",
  "movements": {
    "spider_omni_false": [
      {"moves": {"20": -3.0, "21": 3.0, "22": -8.0, "23": 38.0, "24": -33.0, "25": 33.0, "26": 38.0, "27": -8.0}, "speed": "M"},
      {"moves": {"20": -5.605, "21": 0.395, "22": -8.228, "23": 37.772, "24": -30.395, "25": 35.605, "26": 37.772, "27": -8.228}, "speed": "M"},
      {"moves": {"20": -8.13, "21": -2.13, "22": -8.905, "23": 37.095, "24": -27.87, "25": 38.13, "26": 37.095, "27": -8.905}, "speed": "M"},
      {"moves": {"20": -10.5, "21": -4.5, "22": -10.01, "23": 35.99, "24": -25.5, "25": 40.5, "26": 35.99, "27": -10.01}, "speed": "M"},
      {"moves": {"20": -12.642, "21": -6.642, "22": -11.509, "23": 34.491, "24": -23.358, "25": 42.642, "26": 34.491, "27": -11.509}, "speed": "M"},
      {"moves": {"20": -14.491, "21": -8.491, "22": -13.358, "23": 32.642, "24": -21.509, "25": 44.491, "26": 32.642, "27": -13.358}, "speed": "M"},
      {"moves": {"20": -15.99, "21": -9.99, "22": -15.5, "23": 30.5, "24": -20.01, "25": 45.99, "26": 30.5, "27": -15.5}, "speed": "M"},
      {"moves": {"20": -17.095, "21": -11.095, "22": -17.87, "23": 28.13, "24": -18.905, "25": 47.095, "26": 28.13, "27": -17.87}, "speed": "M"},
      {"moves": {"20": -17.772, "21": -11.772, "22": -20.395, "23": 25.605, "24": -18.228, "25": 47.772, "26": 25.605, "27": -20.395}, "speed": "M"},
      {"moves": {"20": -18.0, "21": -12.0, "22": -23.0, "23": 23.0, "24": -18.0, "25": 48.0, "26": 23.0, "27": -23.0}, "speed": "M"},
      {"moves": {"20": -17.772, "21": -11.772, "22": -25.605, "23": 20.395, "24": -18.228, "25": 47.772, "26": 20.395, "27": -25.605}, "speed": "M"},
      {"moves": {"20": -17.095, "21": -11.095, "22": -28.13, "23": 17.87, "24": -18.905, "25": 47.095, "26": 17.87, "27": -28.13}, "speed": "M"},
      {"moves": {"20": -15.99, "21": -9.99, "22": -30.5, "23": 15.5, "24": -20.01, "25": 45.99, "26": 15.5, "27": -30.5}, "speed": "M"},
      {"moves": {"20": -14.491, "21": -8.491, "22": -32.642, "23": 13.358, "24": -21.509, "25": 44.491, "26": 13.358, "27": -32.642}, "speed": "M"},
      {"moves": {"20": -12.642, "21": -6.642, "22": -34.491, "23": 11.509, "24": -23.358, "25": 42.642, "26": 11.509, "27": -34.491}, "speed": "M"},
      {"moves": {"20": -10.5, "21": -4.5, "22": -35.99, "23": 10.01, "24": -25.5, "25": 40.5, "26": 10.01, "27": -35.99}, "speed": "M"},
      {"moves": {"20": -8.13, "21": -2.13, "22": -37.095, "23": 8.905, "24": -27.87, "25": 38.13, "26": 8.905, "27": -37.095}, "speed": "M"},
      {"moves": {"20": -5.605, "21": 0.395, "22": -37.772, "23": 8.228, "24": -30.395, "25": 35.605, "26": 8.228, "27": -37.772}, "speed": "M"},
      {"moves": {"20": -3.0, "21": 3.0, "22": -38.0, "23": 8.0, "24": -33.0, "25": 33.0, "26": 8.0, "27": -38.0}, "speed": "M"},
      {"moves": {"20": -0.395, "21": 5.605, "22": -37.772, "23": 8.228, "24": -35.605, "25": 30.395, "26": 8.228, "27": -37.772}, "speed": "M"},
      {"moves": {"20": 2.13, "21": 8.13, "22": -37.095, "23": 8.905, "24": -38.13, "25": 27.87, "26": 8.905, "27": -37.095}, "speed": "M"},
      {"moves": {"20": 4.5, "21": 10.5, "22": -35.99, "23": 10.01, "24": -40.5, "25": 25.5, "26": 10.01, "27": -35.99}, "speed": "M"},
      {"moves": {"20": 6.642, "21": 12.642, "22": -34.491, "23": 11.509, "24": -42.642, "25": 23.358, "26": 11.509, "27": -34.491}, "speed": "M"},
      {"moves": {"20": 8.491, "21": 14.491, "22": -32.642, "23": 13.358, "24": -44.491, "25": 21.509, "26": 13.358, "27": -32.642}, "speed": "M"},
      {"moves": {"20": 9.99, "21": 15.99, "22": -30.5, "23": 15.5, "24": -45.99, "25": 20.01, "26": 15.5, "27": -30.5}, "speed": "M"},
      {"moves": {"20": 11.095, "21": 17.095, "22": -28.13, "23": 17.87, "24": -47.095, "25": 18.905, "26": 17.87, "27": -28.13}, "speed": "M"},
      {"moves": {"20": 11.772, "21": 17.772, "22": -25.605, "23": 20.395, "24": -47.772, "25": 18.228, "26": 20.395, "27": -25.605}, "speed": "M"},
      {"moves": {"20": 12.0, "21": 18.0, "22": -23.0, "23": 23.0, "24": -48.0, "25": 18.0, "26": 23.0, "27": -23.0}, "speed": "M"},
      {"moves": {"20": 11.772, "21": 17.772, "22": -20.395, "23": 25.605, "24": -47.772, "25": 18.228, "26": 25.605, "27": -20.395}, "speed": "M"},
      {"moves": {"20": 11.095, "21": 17.095, "22": -17.87, "23": 28.13, "24": -47.095, "25": 18.905, "26": 28.13, "27": -17.87}, "speed": "M"},
      {"moves": {"20": 9.99, "21": 15.99, "22": -15.5, "23": 30.5, "24": -45.99, "25": 20.01, "26": 30.5, "27": -15.5}, "speed": "M"},
      {"moves": {"20": 8.491, "21": 14.491, "22": -13.358, "23": 32.642, "24": -44.491, "25": 21.509, "26": 32.642, "27": -13.358}, "speed": "M"},
      {"moves": {"20": 6.642, "21": 12.642, "22": -11.509, "23": 34.491, "24": -42.642, "25": 23.358, "26": 34.491, "27": -11.509}, "speed": "M"},
      {"moves": {"20": 4.5, "21": 10.5, "22": -10.01, "23": 35.99, "24": -40.5, "25": 25.5, "26": 35.99, "27": -10.01}, "speed": "M"},
      {"moves": {"20": 2.13, "21": 8.13, "22": -8.905, "23": 37.095, "24": -38.13, "25": 27.87, "26": 37.095, "27": -8.905}, "speed": "M"},
      {"moves": {"20": -0.395, "21": 5.605, "22": -8.228, "23": 37.772, "24": -35.605, "25": 30.395, "26": 37.772, "27": -8.228}, "speed": "M"},
      {"moves": {"20": -3.0, "21": 3.0, "22": -8.0, "23": 38.0, "24": -33.0, "25": 33.0, "26": 38.0, "27": -8.0}, "speed": "M"}
    ]
  }
}
```

#### 15. spider_walk_forward

Complete sequence: 37 steps.

```json
{
  "robot_type": "spider",
  "movements": {
    "spider_walk_forward": [
      {"moves": {"20": 35.0, "21": -5.0, "22": -10.0, "23": 10.0, "24": -35.0, "25": 5.0, "26": 10.0, "27": -10.0}, "speed": "M"},
      {"moves": {"20": 34.772, "21": -5.228, "22": -8.794, "23": 8.794, "24": -34.772, "25": 5.228, "26": 8.794, "27": -8.794}, "speed": "M"},
      {"moves": {"20": 34.095, "21": -5.905, "22": -5.321, "23": 5.321, "24": -34.095, "25": 5.905, "26": 5.321, "27": -5.321}, "speed": "M"},
      {"moves": {"20": 32.99, "21": -7.01, "22": 0.0, "23": 0.0, "24": -32.99, "25": 7.01, "26": 0.0, "27": 0.0}, "speed": "M"},
      {"moves": {"20": 31.491, "21": -8.509, "22": 6.527, "23": -6.527, "24": -31.491, "25": 8.509, "26": -6.527, "27": 6.527}, "speed": "M"},
      {"moves": {"20": 29.642, "21": -10.358, "22": 13.473, "23": -13.473, "24": -29.642, "25": 10.358, "26": -13.473, "27": 13.473}, "speed": "M"},
      {"moves": {"20": 27.5, "21": -12.5, "22": 20.0, "23": -20.0, "24": -27.5, "25": 12.5, "26": -20.0, "27": 20.0}, "speed": "M"},
      {"moves": {"20": 25.13, "21": -14.87, "22": 25.321, "23": -25.321, "24": -25.13, "25": 14.87, "26": -25.321, "27": 25.321}, "speed": "M"},
      {"moves": {"20": 22.605, "21": -17.395, "22": 28.794, "23": -28.794, "24": -22.605, "25": 17.395, "26": -28.794, "27": 28.794}, "speed": "M"},
      {"moves": {"20": 20.0, "21": -20.0, "22": 30.0, "23": -30.0, "24": -20.0, "25": 20.0, "26": -30.0, "27": 30.0}, "speed": "M"},
      {"moves": {"20": 17.395, "21": -22.605, "22": 28.794, "23": -28.794, "24": -17.395, "25": 22.605, "26": -28.794, "27": 28.794}, "speed": "M"},
      {"moves": {"20": 14.87, "21": -25.13, "22": 25.321, "23": -25.321, "24": -14.87, "25": 25.13, "26": -25.321, "27": 25.321}, "speed": "M"},
      {"moves": {"20": 12.5, "21": -27.5, "22": 20.0, "23": -20.0, "24": -12.5, "25": 27.5, "26": -20.0, "27": 20.0}, "speed": "M"},
      {"moves": {"20": 10.358, "21": -29.642, "22": 13.473, "23": -13.473, "24": -10.358, "25": 29.642, "26": -13.473, "27": 13.473}, "speed": "M"},
      {"moves": {"20": 8.509, "21": -31.491, "22": 6.527, "23": -6.527, "24": -8.509, "25": 31.491, "26": -6.527, "27": 6.527}, "speed": "M"},
      {"moves": {"20": 7.01, "21": -32.99, "22": 0.0, "23": 0.0, "24": -7.01, "25": 32.99, "26": 0.0, "27": 0.0}, "speed": "M"},
      {"moves": {"20": 5.905, "21": -34.095, "22": -5.321, "23": 5.321, "24": -5.905, "25": 34.095, "26": 5.321, "27": -5.321}, "speed": "M"},
      {"moves": {"20": 5.228, "21": -34.772, "22": -8.794, "23": 8.794, "24": -5.228, "25": 34.772, "26": 8.794, "27": -8.794}, "speed": "M"},
      {"moves": {"20": 5.0, "21": -35.0, "22": -10.0, "23": 10.0, "24": -5.0, "25": 35.0, "26": 10.0, "27": -10.0}, "speed": "M"},
      {"moves": {"20": 5.228, "21": -34.772, "22": -8.794, "23": 8.794, "24": -5.228, "25": 34.772, "26": 8.794, "27": -8.794}, "speed": "M"},
      {"moves": {"20": 5.905, "21": -34.095, "22": -5.321, "23": 5.321, "24": -5.905, "25": 34.095, "26": 5.321, "27": -5.321}, "speed": "M"},
      {"moves": {"20": 7.01, "21": -32.99, "22": 0.0, "23": 0.0, "24": -7.01, "25": 32.99, "26": 0.0, "27": 0.0}, "speed": "M"},
      {"moves": {"20": 8.509, "21": -31.491, "22": 6.527, "23": -6.527, "24": -8.509, "25": 31.491, "26": -6.527, "27": 6.527}, "speed": "M"},
      {"moves": {"20": 10.358, "21": -29.642, "22": 13.473, "23": -13.473, "24": -10.358, "25": 29.642, "26": -13.473, "27": 13.473}, "speed": "M"},
      {"moves": {"20": 12.5, "21": -27.5, "22": 20.0, "23": -20.0, "24": -12.5, "25": 27.5, "26": -20.0, "27": 20.0}, "speed": "M"},
      {"moves": {"20": 14.87, "21": -25.13, "22": 25.321, "23": -25.321, "24": -14.87, "25": 25.13, "26": -25.321, "27": 25.321}, "speed": "M"},
      {"moves": {"20": 17.395, "21": -22.605, "22": 28.794, "23": -28.794, "24": -17.395, "25": 22.605, "26": -28.794, "27": 28.794}, "speed": "M"},
      {"moves": {"20": 20.0, "21": -20.0, "22": 30.0, "23": -30.0, "24": -20.0, "25": 20.0, "26": -30.0, "27": 30.0}, "speed": "M"},
      {"moves": {"20": 22.605, "21": -17.395, "22": 28.794, "23": -28.794, "24": -22.605, "25": 17.395, "26": -28.794, "27": 28.794}, "speed": "M"},
      {"moves": {"20": 25.13, "21": -14.87, "22": 25.321, "23": -25.321, "24": -25.13, "25": 14.87, "26": -25.321, "27": 25.321}, "speed": "M"},
      {"moves": {"20": 27.5, "21": -12.5, "22": 20.0, "23": -20.0, "24": -27.5, "25": 12.5, "26": -20.0, "27": 20.0}, "speed": "M"},
      {"moves": {"20": 29.642, "21": -10.358, "22": 13.473, "23": -13.473, "24": -29.642, "25": 10.358, "26": -13.473, "27": 13.473}, "speed": "M"},
      {"moves": {"20": 31.491, "21": -8.509, "22": 6.527, "23": -6.527, "24": -31.491, "25": 8.509, "26": -6.527, "27": 6.527}, "speed": "M"},
      {"moves": {"20": 32.99, "21": -7.01, "22": 0.0, "23": 0.0, "24": -32.99, "25": 7.01, "26": 0.0, "27": 0.0}, "speed": "M"},
      {"moves": {"20": 34.095, "21": -5.905, "22": -5.321, "23": 5.321, "24": -34.095, "25": 5.905, "26": 5.321, "27": -5.321}, "speed": "M"},
      {"moves": {"20": 34.772, "21": -5.228, "22": -8.794, "23": 8.794, "24": -34.772, "25": 5.228, "26": 8.794, "27": -8.794}, "speed": "M"},
      {"moves": {"20": 35.0, "21": -5.0, "22": -10.0, "23": 10.0, "24": -35.0, "25": 5.0, "26": 10.0, "27": -10.0}, "speed": "M"}
    ]
  }
}
```

#### 16. spider_walk_backward

Complete sequence: 37 steps.

```json
{
  "robot_type": "spider",
  "movements": {
    "spider_walk_backward": [
      {"moves": {"20": 5.0, "21": -35.0, "22": -10.0, "23": 10.0, "24": -5.0, "25": 35.0, "26": 10.0, "27": -10.0}, "speed": "M"},
      {"moves": {"20": 5.228, "21": -34.772, "22": -8.794, "23": 8.794, "24": -5.228, "25": 34.772, "26": 8.794, "27": -8.794}, "speed": "M"},
      {"moves": {"20": 5.905, "21": -34.095, "22": -5.321, "23": 5.321, "24": -5.905, "25": 34.095, "26": 5.321, "27": -5.321}, "speed": "M"},
      {"moves": {"20": 7.01, "21": -32.99, "22": 0.0, "23": 0.0, "24": -7.01, "25": 32.99, "26": 0.0, "27": 0.0}, "speed": "M"},
      {"moves": {"20": 8.509, "21": -31.491, "22": 6.527, "23": -6.527, "24": -8.509, "25": 31.491, "26": -6.527, "27": 6.527}, "speed": "M"},
      {"moves": {"20": 10.358, "21": -29.642, "22": 13.473, "23": -13.473, "24": -10.358, "25": 29.642, "26": -13.473, "27": 13.473}, "speed": "M"},
      {"moves": {"20": 12.5, "21": -27.5, "22": 20.0, "23": -20.0, "24": -12.5, "25": 27.5, "26": -20.0, "27": 20.0}, "speed": "M"},
      {"moves": {"20": 14.87, "21": -25.13, "22": 25.321, "23": -25.321, "24": -14.87, "25": 25.13, "26": -25.321, "27": 25.321}, "speed": "M"},
      {"moves": {"20": 17.395, "21": -22.605, "22": 28.794, "23": -28.794, "24": -17.395, "25": 22.605, "26": -28.794, "27": 28.794}, "speed": "M"},
      {"moves": {"20": 20.0, "21": -20.0, "22": 30.0, "23": -30.0, "24": -20.0, "25": 20.0, "26": -30.0, "27": 30.0}, "speed": "M"},
      {"moves": {"20": 22.605, "21": -17.395, "22": 28.794, "23": -28.794, "24": -22.605, "25": 17.395, "26": -28.794, "27": 28.794}, "speed": "M"},
      {"moves": {"20": 25.13, "21": -14.87, "22": 25.321, "23": -25.321, "24": -25.13, "25": 14.87, "26": -25.321, "27": 25.321}, "speed": "M"},
      {"moves": {"20": 27.5, "21": -12.5, "22": 20.0, "23": -20.0, "24": -27.5, "25": 12.5, "26": -20.0, "27": 20.0}, "speed": "M"},
      {"moves": {"20": 29.642, "21": -10.358, "22": 13.473, "23": -13.473, "24": -29.642, "25": 10.358, "26": -13.473, "27": 13.473}, "speed": "M"},
      {"moves": {"20": 31.491, "21": -8.509, "22": 6.527, "23": -6.527, "24": -31.491, "25": 8.509, "26": -6.527, "27": 6.527}, "speed": "M"},
      {"moves": {"20": 32.99, "21": -7.01, "22": 0.0, "23": 0.0, "24": -32.99, "25": 7.01, "26": 0.0, "27": 0.0}, "speed": "M"},
      {"moves": {"20": 34.095, "21": -5.905, "22": -5.321, "23": 5.321, "24": -34.095, "25": 5.905, "26": 5.321, "27": -5.321}, "speed": "M"},
      {"moves": {"20": 34.772, "21": -5.228, "22": -8.794, "23": 8.794, "24": -34.772, "25": 5.228, "26": 8.794, "27": -8.794}, "speed": "M"},
      {"moves": {"20": 35.0, "21": -5.0, "22": -10.0, "23": 10.0, "24": -35.0, "25": 5.0, "26": 10.0, "27": -10.0}, "speed": "M"},
      {"moves": {"20": 34.772, "21": -5.228, "22": -8.794, "23": 8.794, "24": -34.772, "25": 5.228, "26": 8.794, "27": -8.794}, "speed": "M"},
      {"moves": {"20": 34.095, "21": -5.905, "22": -5.321, "23": 5.321, "24": -34.095, "25": 5.905, "26": 5.321, "27": -5.321}, "speed": "M"},
      {"moves": {"20": 32.99, "21": -7.01, "22": 0.0, "23": 0.0, "24": -32.99, "25": 7.01, "26": 0.0, "27": 0.0}, "speed": "M"},
      {"moves": {"20": 31.491, "21": -8.509, "22": 6.527, "23": -6.527, "24": -31.491, "25": 8.509, "26": -6.527, "27": 6.527}, "speed": "M"},
      {"moves": {"20": 29.642, "21": -10.358, "22": 13.473, "23": -13.473, "24": -29.642, "25": 10.358, "26": -13.473, "27": 13.473}, "speed": "M"},
      {"moves": {"20": 27.5, "21": -12.5, "22": 20.0, "23": -20.0, "24": -27.5, "25": 12.5, "26": -20.0, "27": 20.0}, "speed": "M"},
      {"moves": {"20": 25.13, "21": -14.87, "22": 25.321, "23": -25.321, "24": -25.13, "25": 14.87, "26": -25.321, "27": 25.321}, "speed": "M"},
      {"moves": {"20": 22.605, "21": -17.395, "22": 28.794, "23": -28.794, "24": -22.605, "25": 17.395, "26": -28.794, "27": 28.794}, "speed": "M"},
      {"moves": {"20": 20.0, "21": -20.0, "22": 30.0, "23": -30.0, "24": -20.0, "25": 20.0, "26": -30.0, "27": 30.0}, "speed": "M"},
      {"moves": {"20": 17.395, "21": -22.605, "22": 28.794, "23": -28.794, "24": -17.395, "25": 22.605, "26": -28.794, "27": 28.794}, "speed": "M"},
      {"moves": {"20": 14.87, "21": -25.13, "22": 25.321, "23": -25.321, "24": -14.87, "25": 25.13, "26": -25.321, "27": 25.321}, "speed": "M"},
      {"moves": {"20": 12.5, "21": -27.5, "22": 20.0, "23": -20.0, "24": -12.5, "25": 27.5, "26": -20.0, "27": 20.0}, "speed": "M"},
      {"moves": {"20": 10.358, "21": -29.642, "22": 13.473, "23": -13.473, "24": -10.358, "25": 29.642, "26": -13.473, "27": 13.473}, "speed": "M"},
      {"moves": {"20": 8.509, "21": -31.491, "22": 6.527, "23": -6.527, "24": -8.509, "25": 31.491, "26": -6.527, "27": 6.527}, "speed": "M"},
      {"moves": {"20": 7.01, "21": -32.99, "22": 0.0, "23": 0.0, "24": -7.01, "25": 32.99, "26": 0.0, "27": 0.0}, "speed": "M"},
      {"moves": {"20": 5.905, "21": -34.095, "22": -5.321, "23": 5.321, "24": -5.905, "25": 34.095, "26": 5.321, "27": -5.321}, "speed": "M"},
      {"moves": {"20": 5.228, "21": -34.772, "22": -8.794, "23": 8.794, "24": -5.228, "25": 34.772, "26": 8.794, "27": -8.794}, "speed": "M"},
      {"moves": {"20": 5.0, "21": -35.0, "22": -10.0, "23": 10.0, "24": -5.0, "25": 35.0, "26": 10.0, "27": -10.0}, "speed": "M"}
    ]
  }
}
```

#### 17. spider_jump

Complete sequence: 3 steps.

```json
{
  "robot_type": "spider",
  "movements": {
    "spider_jump": [
      {"moves": {"20": -20.0, "21": 20.0, "22": -60.0, "23": 60.0, "24": -15.0, "25": 15.0, "26": 60.0, "27": -60.0}, "speed": "M"},
      {"moves": {"20": 60.0, "21": -60.0, "22": 80.0, "23": -80.0, "24": -20.0, "25": 20.0, "26": -80.0, "27": 80.0}, "speed": "M"},
      {"moves": {"20": 20.0, "21": -20.0, "22": 0.0, "23": 0.0, "24": -20.0, "25": 20.0, "26": 0.0, "27": 0.0}, "speed": "M"}
    ]
  }
}
```

#### 18. spider_scared

Complete sequence: 3 steps.

```json
{
  "robot_type": "spider",
  "movements": {
    "spider_scared": [
      {"moves": {"20": 60.0, "21": -60.0, "22": 80.0, "23": -80.0, "24": -20.0, "25": 20.0, "26": -80.0, "27": 80.0}, "speed": "M"},
      {"moves": {"20": -20.0, "21": 20.0, "22": -60.0, "23": 60.0, "24": -15.0, "25": 15.0, "26": 60.0, "27": -60.0}, "speed": "M"},
      {"moves": {"20": 20.0, "21": -20.0, "22": 0.0, "23": 0.0, "24": -20.0, "25": 20.0, "26": 0.0, "27": 0.0}, "speed": "M"}
    ]
  }
}
```

#### 19. spider_hello

Complete sequence: 39 steps.

```json
{
  "robot_type": "spider",
  "movements": {
    "spider_hello": [
      {"moves": {"20": -1.333, "21": 1.333, "22": -0.667, "23": 0.667, "24": -1.0, "25": 1.0, "26": 4.333, "27": -4.333}, "speed": "M"},
      {"moves": {"20": 0.4, "21": -0.4, "22": -0.2, "23": 0.2, "24": -1.4, "25": 1.4, "26": 0.0, "27": 0.0}, "speed": "M"},
      {"moves": {"20": -20.0, "21": 20.0, "22": 0.0, "23": 65.0, "24": -50.0, "25": 15.0, "26": 60.0, "27": -10.0}, "speed": "M"},
      {"moves": {"20": -20.0, "21": 20.0, "22": 0.0, "23": 65.0, "24": -41.318, "25": 15.0, "26": 59.24, "27": -10.0}, "speed": "M"},
      {"moves": {"20": -20.0, "21": 20.0, "22": 0.0, "23": 65.0, "24": -32.899, "25": 15.0, "26": 56.985, "27": -10.0}, "speed": "M"},
      {"moves": {"20": -20.0, "21": 20.0, "22": 0.0, "23": 65.0, "24": -25.0, "25": 15.0, "26": 53.301, "27": -10.0}, "speed": "M"},
      {"moves": {"20": -20.0, "21": 20.0, "22": 0.0, "23": 65.0, "24": -17.861, "25": 15.0, "26": 48.302, "27": -10.0}, "speed": "M"},
      {"moves": {"20": -20.0, "21": 20.0, "22": 0.0, "23": 65.0, "24": -11.698, "25": 15.0, "26": 42.139, "27": -10.0}, "speed": "M"},
      {"moves": {"20": -20.0, "21": 20.0, "22": 0.0, "23": 65.0, "24": -6.699, "25": 15.0, "26": 35.0, "27": -10.0}, "speed": "M"},
      {"moves": {"20": -20.0, "21": 20.0, "22": 0.0, "23": 65.0, "24": -3.015, "25": 15.0, "26": 27.101, "27": -10.0}, "speed": "M"},
      {"moves": {"20": -20.0, "21": 20.0, "22": 0.0, "23": 65.0, "24": -0.76, "25": 15.0, "26": 18.682, "27": -10.0}, "speed": "M"},
      {"moves": {"20": -20.0, "21": 20.0, "22": 0.0, "23": 65.0, "24": 0.0, "25": 15.0, "26": 10.0, "27": -10.0}, "speed": "M"},
      {"moves": {"20": -20.0, "21": 20.0, "22": 0.0, "23": 65.0, "24": -0.76, "25": 15.0, "26": 1.318, "27": -10.0}, "speed": "M"},
      {"moves": {"20": -20.0, "21": 20.0, "22": 0.0, "23": 65.0, "24": -3.015, "25": 15.0, "26": -7.101, "27": -10.0}, "speed": "M"},
      {"moves": {"20": -20.0, "21": 20.0, "22": 0.0, "23": 65.0, "24": -6.699, "25": 15.0, "26": -15.0, "27": -10.0}, "speed": "M"},
      {"moves": {"20": -20.0, "21": 20.0, "22": 0.0, "23": 65.0, "24": -11.698, "25": 15.0, "26": -22.139, "27": -10.0}, "speed": "M"},
      {"moves": {"20": -20.0, "21": 20.0, "22": 0.0, "23": 65.0, "24": -17.861, "25": 15.0, "26": -28.302, "27": -10.0}, "speed": "M"},
      {"moves": {"20": -20.0, "21": 20.0, "22": 0.0, "23": 65.0, "24": -25.0, "25": 15.0, "26": -33.301, "27": -10.0}, "speed": "M"},
      {"moves": {"20": -20.0, "21": 20.0, "22": 0.0, "23": 65.0, "24": -32.899, "25": 15.0, "26": -36.985, "27": -10.0}, "speed": "M"},
      {"moves": {"20": -20.0, "21": 20.0, "22": 0.0, "23": 65.0, "24": -41.318, "25": 15.0, "26": -39.24, "27": -10.0}, "speed": "M"},
      {"moves": {"20": -20.0, "21": 20.0, "22": 0.0, "23": 65.0, "24": -50.0, "25": 15.0, "26": -40.0, "27": -10.0}, "speed": "M"},
      {"moves": {"20": -20.0, "21": 20.0, "22": 0.0, "23": 65.0, "24": -58.682, "25": 15.0, "26": -39.24, "27": -10.0}, "speed": "M"},
      {"moves": {"20": -20.0, "21": 20.0, "22": 0.0, "23": 65.0, "24": -67.101, "25": 15.0, "26": -36.985, "27": -10.0}, "speed": "M"},
      {"moves": {"20": -20.0, "21": 20.0, "22": 0.0, "23": 65.0, "24": -75.0, "25": 15.0, "26": -33.301, "27": -10.0}, "speed": "M"},
      {"moves": {"20": -20.0, "21": 20.0, "22": 0.0, "23": 65.0, "24": -82.139, "25": 15.0, "26": -28.302, "27": -10.0}, "speed": "M"},
      {"moves": {"20": -20.0, "21": 20.0, "22": 0.0, "23": 65.0, "24": -88.302, "25": 15.0, "26": -22.139, "27": -10.0}, "speed": "M"},
      {"moves": {"20": -20.0, "21": 20.0, "22": 0.0, "23": 65.0, "24": -90.0, "25": 15.0, "26": -15.0, "27": -10.0}, "speed": "M"},
      {"moves": {"20": -20.0, "21": 20.0, "22": 0.0, "23": 65.0, "24": -90.0, "25": 15.0, "26": -7.101, "27": -10.0}, "speed": "M"},
      {"moves": {"20": -20.0, "21": 20.0, "22": 0.0, "23": 65.0, "24": -90.0, "25": 15.0, "26": 1.318, "27": -10.0}, "speed": "M"},
      {"moves": {"20": -20.0, "21": 20.0, "22": 0.0, "23": 65.0, "24": -90.0, "25": 15.0, "26": 10.0, "27": -10.0}, "speed": "M"},
      {"moves": {"20": -20.0, "21": 20.0, "22": 0.0, "23": 65.0, "24": -90.0, "25": 15.0, "26": 18.682, "27": -10.0}, "speed": "M"},
      {"moves": {"20": -20.0, "21": 20.0, "22": 0.0, "23": 65.0, "24": -90.0, "25": 15.0, "26": 27.101, "27": -10.0}, "speed": "M"},
      {"moves": {"20": -20.0, "21": 20.0, "22": 0.0, "23": 65.0, "24": -90.0, "25": 15.0, "26": 35.0, "27": -10.0}, "speed": "M"},
      {"moves": {"20": -20.0, "21": 20.0, "22": 0.0, "23": 65.0, "24": -88.302, "25": 15.0, "26": 42.139, "27": -10.0}, "speed": "M"},
      {"moves": {"20": -20.0, "21": 20.0, "22": 0.0, "23": 65.0, "24": -82.139, "25": 15.0, "26": 48.302, "27": -10.0}, "speed": "M"},
      {"moves": {"20": -20.0, "21": 20.0, "22": 0.0, "23": 65.0, "24": -75.0, "25": 15.0, "26": 53.301, "27": -10.0}, "speed": "M"},
      {"moves": {"20": -20.0, "21": 20.0, "22": 0.0, "23": 65.0, "24": -67.101, "25": 15.0, "26": 56.985, "27": -10.0}, "speed": "M"},
      {"moves": {"20": -20.0, "21": 20.0, "22": 0.0, "23": 65.0, "24": -58.682, "25": 15.0, "26": 59.24, "27": -10.0}, "speed": "M"},
      {"moves": {"20": -20.0, "21": 20.0, "22": 0.0, "23": 65.0, "24": -50.0, "25": 15.0, "26": 60.0, "27": -10.0}, "speed": "M"}
    ]
  }
}
```
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

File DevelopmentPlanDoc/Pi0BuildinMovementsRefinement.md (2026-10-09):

# Pi0 built-in movement refinement: a separate timed controller

Date: 2026-10-09. **Design proposal for future development; not implemented.**

A separate built-in movement controller is feasible. It can preserve OTTO's shared oscillator clock and explicit pauses more faithfully than the current waypoint executor. It needs its own validated program format, scheduler, cancellation token, and exclusive access to the servo outputs. Adding duration or oscillator fields to today's movement JSON would not achieve this: the existing controller does not read them.

The approved implementation is described in [SpiderBuildinMovements.md](SpiderBuildinMovements.md). Its 19 opt-in entries cover 16 OTTO methods and selected directional variants using existing `moves`, `speed`, and optional `per_servo_speeds` conventions. **No existing NinjaRobotPi0 movement-control function has been changed.** This document does not authorize or implement a replacement, new endpoint, hardware test, or automatic configuration migration.

## 1. Evidence and present behavior

The local `ninjarobot_pi0_Wiki` was retrieved using `python3 scripts/wiki.py search "moves per_servo_speeds speed"` and movement/servo searches. Relevant pages are [Motion System and Easing](../ninjarobot_pi0_Wiki/wiki/concepts/motion-system-and-easing.md), [pi0servo](../ninjarobot_pi0_Wiki/wiki/entities/pi0servo.md), and [API and CLI Reference](../ninjarobot_pi0_Wiki/wiki/references/api-and-cli-reference.md). They are draft and unverified, with recorded AI semantic reviews; this is not physical or human verification. Source IDs include `src-20260822-readme-7` and `src-20260822-developmentguide`. Current manuals are resolved through [project-knowledge.json](../ninjarobot_pi0_Wiki/project-knowledge.json).

Code inspection takes precedence where broad wiki wording such as “simultaneous” or “preserves momentum” suggests stronger timing guarantees. The current implementation shares a loop start time, but does not enforce common arrival or continuity of velocity across waypoints.

| Contract | Verified implementation | Consequence for translation |
|---|---|---|
| `moves` | GPIO-to-angle object; string keys become integers; targets ordered by the actual driver pin list | Preserve GPIO identity, never assume list index equals OTTO ID |
| `speed` | Required step key; native modes F/M/S | A velocity choice, not a period or duration |
| `per_servo_speeds` | Optional GPIO-to-mode overrides; fallback is step speed | Changes each joint's travel time independently |
| Missing target | Driver receives `None` for that pin | No new command, not an implicit neutral pose |
| Unknown pin | Silently absent from ordered driver targets | Future validator should reject it |
| Easing | Single step in/out cubic; first in cubic, middle linear, last out cubic | Endpoint shape is executor-selected, not a stored curve |
| Completion | Waits for maximum of the individual servo durations | Shorter-distance joints can arrive sooner |
| Delay / period / repeat | No such fields are consumed | Extra JSON keys cannot add scheduling |
| Validation | `NinjaConfig.movements` is `Dict[str, list]` | Outer shape validation does not validate each step |
| Position knowledge | Last command, then pulse-derived estimate, then calibration center | No encoder feedback or proof of arrival |
| Cancellation | `abort_check` is not polled or forwarded; unsuccessful driver move plus a truthy callback triggers centering and `EmergencyStop` | Existing callback is not a reliable continuous cancellation contract |

Primary locations: [MovementController](../ninja_core/src/ninja_core/movement_controller.py), [configuration](../ninja_core/src/ninja_core/config.py), [ServoGroup](../pi0servo/src/pi0servo/core/multi_servos.py), [duration calculator](../pi0servo/src/pi0servo/motion/calculator.py), [Servo](../pi0servo/src/pi0servo/core/servo.py), and [HAL servo setup](../ninja_core/src/ninja_core/hal.py). Source OTTO parameters and bugs were cross-checked against the unchanged umbrella-workspace `RoboticsRepoReference/OTTOquad-master/firmwareVER_9/OTTOKame.cpp`, `Octosnake.cpp`, and `OttoQuadMovementIntro.md`.

### A current, executable-format example

This is an entry inside the existing `movements` object:

```json
{
  "example": [
    {"moves": {"20": 20, "21": -20}, "speed": "M", "per_servo_speeds": {"21": "S"}},
    {"moves": {"20": 0}, "speed": "M"}
  ]
}
```

GPIO20 uses M and GPIO21 uses S in the first step. The second step only commands GPIO20. It does not wait for an added pause or center GPIO21. Repeating an unchanged target has zero calculated travel time, so it cannot stand in for a dwell.

The driver's nominal velocity is `600 × calibration_speed_percent / 100 × mode_multiplier` degrees/second, where F=1, M=0.75, S=0.5. Duration is absolute angular distance divided by this velocity. For two joints starting at zero, a linear 20° move at 80% calibration speed takes about 55.6 ms in M or 83.3 ms in S. Cubic easing changes instantaneous velocity; these calculated durations do not guarantee physical speed or arrival. The 600°/s constant is an assumed motor specification, not a measurement of this Spider. A nonpositive calculated velocity produces zero duration in the present code; **speed zero must not be interpreted as a stop command**.

## 2. What can be preserved

| OTTO feature | Existing waypoint pack | Proposed separate controller |
|---|---|---|
| Logical pose and corrected GPIO mapping | Yes, nominal q−90; mounting still unverified | Yes, through an explicit validated robot profile |
| Sine amplitude/offset/phase | Sampled positions only | Analytic evaluation on one clock |
| Period T and per-joint T/2 | Stored as generator provenance only | Explicit period per joint |
| Pause following a pose command | Unsupported | Cancellable dwell action |
| Continuous oscillator refresh | Finite one-cycle samples | Finite cycles first; explicit continuous mode later |
| Common arrival for a timed pose | No | Shared interpolation duration |
| OTTO `steps` | Source `execute()` ignores it | Deliberate finite-cycle semantics, clearly a correction |
| Source calibration/reversal | Not copied without Pi0 evidence | Separate measured profile; no inferred inversion |
| Source history-dependent helper bugs | Partial representative hello sequence | Must choose literal emulation or corrected intent |
| Physical foot contact, load and balance | Unverified | Still requires physical validation |

The useful fidelity target is the **logical commanded trajectory**, not identical mechanical motion. Source oscillator periods do not establish that a loaded Pi0 servo can follow them. Pi0 OS scheduling and sequential GPIO writes also prevent a promise of perfectly simultaneous physical motion.

## 3. Proposed architecture and compatibility boundary

Add a separate module, provisionally `builtin_movement_controller.py`, with a `BuiltinMovementController` and a distinct program registry, provisionally `builtin_movements`. Names and paths here are proposals, not existing imports or API fields. Keep `MovementController`, its configuration, native speed meanings, recording format, and existing API responses unchanged.

```mermaid
flowchart TD
  A["Existing config.movements"] --> B["Existing MovementController"]
  C["Separate versioned built-in registry"] --> D["Validate and compile logical program"]
  D --> E["New timed scheduler: one monotonic clock"]
  B --> F["Exclusive servo ownership required at integration boundary"]
  E --> F
  F --> G["Existing calibrated servo output"]
  H["Stop / mode switch"] --> E
```

The ownership box is a **future integration requirement**, not an existing universal lock. [runtime_pipeline.py](../ninja_core/src/ninja_core/runtime_pipeline.py) coordinates native/Blockly mode and requests aborts, but is not a lock around every servo writer or proof that an earlier writer has joined. A standalone new class is insufficient if a web request, Blockly action, native animation, centering request, or shutdown action can write concurrently.

A future integration phase should provide one owner at a time, reject or explicitly replace overlapping requests, cancel and join the old owner before handing over, and prevent a stale worker from writing after ownership changes. Prefer an additive orchestration adapter around call sites; any necessary existing call-site edits require a separately reviewed implementation plan. If complete ownership cannot be enforced without changing existing entry points, ship only an isolated opt-in runner until that integration is approved. Do not publish a concurrent endpoint prematurely.

The new scheduler can evaluate trajectories in one worker and use the existing calibrated `Servo.set_angle` output through an adapter. It must not call `move_all_sync` once per sample: that method adds distance-based timing/easing and resets its own abort flags at each entry. Reusing that loop would distort phase and risk losing cancellation between samples. Reusing calibrated output does not automatically reuse motion speed limits; the new compiler must enforce those separately.

### Clock and execution contract

- Use a monotonic clock and absolute deadlines, evaluating every commanded joint from the same elapsed time. A provisional 10 ms tick matches the present loop interval, but is not a measured Pi timing guarantee.
- If late, evaluate the current phase rather than replaying a queue of stale samples. Record skipped deadlines and peak lateness. Set an explicit lateness threshold that aborts rather than silently stretching an individual joint.
- Validate the entire finite program before acquiring outputs. Keep continuous programs bounded in memory; do not expand infinite lists.
- Check a scheduler-owned cancellation token before writes, between joint writes, during waits and dwells, and between actions. A cancellation can occur partway through a multi-joint frame; report the last issued command and do not claim atomic output.
- On cancellation, stop generating targets and retain the last commanded pulse by default. Whether to hold, release, or move to a recovery pose must be an explicit robot policy; automatic centering can itself cause motion or instability. Command cancellation is not power isolation.
- A hardware fault stops further actions, records failure, and releases software ownership after the worker exits. No automatic retry of a failed physical command. Cleanup must not send an unrequested home pose.
- Command completion means the scheduled final target was issued, not that measured physical arrival occurred. Record both planned duration and actual wall time.

## 4. Proposed program format — not accepted by today's executor

Use a separate, strictly validated `schema_version: 1` document. Do not mix these fields into `config.movements` or silently reinterpret existing speed values. A proposed program has a robot-profile reference, entry policy, actions and explicit completion policy. Reject unknown fields and nonfinite values, booleans masquerading as numbers, duplicate/unknown GPIOs, invalid units, nonpositive periods, negative durations and unbounded repetition unless explicitly supported.

| Proposed action/field | Meaning |
|---|---|
| `pose` / `moves` / `duration_ms` / `curve` | Interpolate from last known commanded state to target over one shared positive duration; curve linear or explicitly named easing |
| `dwell` / `duration_ms` | Issue no new target, retain pulse output and wait cancellably |
| `oscillate` / `joints` / `run_for_ms` | Per GPIO: signed `amplitude_deg`, `offset_deg`, `phase_deg`, positive `period_ms`; evaluate all from one phase epoch |
| `entry` | Before starting an oscillator clock, approach its t=0 pose with validated velocity; entry time is outside `run_for_ms` |
| `limit_policy` | Reject infeasible program by default; optional whole-program timing stretch must be explicit and reported |
| `on_complete` | Hold final target by default; home/release only as an explicit policy |

For clarity, the examples below show **action fragments**. They are illustrative specifications for a future schema, not runnable configuration for either controller today. A complete future program must include its version, measured profile, entry policy and completion policy.

A normal timed pose uses a positive duration. A separate privileged `pose_write` action may be considered for literal OTTO instantaneous-command sequences; it bypasses trajectory velocity shaping and should be disabled in the initial implementation. Do not overload zero duration to secretly mean instant output. A “pause after command” and a “pause after a timed transition completes” are different semantics.

### Speed and timing policy

Keep old F/M/S behavior unchanged in the old controller. In the new schema, use explicit degrees/second limits from an approved profile. An optional compatibility adapter could resolve F/M/S to the current calculation, including per-servo overrides, but must label them nominal software limits and must not mutate the old configuration.

For `angle(t) = offset + amplitude × sin(2πt/period + phase)`, the maximum commanded angular velocity is `2π × abs(amplitude) / period_seconds`. A per-joint limit must constrain this peak, not the average step distance. For a pose interpolation `start + delta × e(u)`, the peak is `abs(delta) × max(abs(e′(u))) / duration_seconds`: linear multiplier 1, the current cubic curves peak at 3. Check acceleration/jerk and mechanical loading separately; satisfying velocity alone is insufficient.

If any joint fails, reject by default or stretch **all coupled periods and related action times by one reported factor**. Slowing one leg independently changes phase relationships. Do not silently clip amplitudes or independently clamp samples; that changes the gait. Explicit legacy clipping (such as hello) belongs in a separately named, reviewed adaptation.

| Source example | Nominal peak | Comparison to hypothetical M at 80% = 360°/s |
|---|---:|---|
| run: A=15°, T=550 ms | 171.36°/s | Below nominal ceiling; not physical approval |
| waveHAND: abs(A)=20°, T=700 ms | 179.52°/s | Below nominal ceiling |
| walk foot: A=20°, T=275 ms | 456.96°/s | Above ceiling; reject or stretch |
| hello moving joint: A=50°, T=350 ms | 897.60°/s before clipping | Above ceiling; also exceeds one angle bound |

Walk needs at least 349.07 ms foot period and 698.14 ms hip period at that hypothetical ceiling (common factor about 1.2694). Real measured limits may demand slower motion. Limits must be checked after direction/offset transformation and for transitions into and out of the wave, not only within its cycle.

## 5. GPIO, calibration and transformation

Use the approved mapping from [SpiderBuildinMovements.md](SpiderBuildinMovements.md#3-spider-hardware-and-servo-mapping): S0→25, S1→24, S2→27, S3→26, S4→21, S5→20, S6→23, S7→22. All are BCM GPIOs. With nominal orientation, target amplitude stays the same, offset becomes `source_offset−90`, phase and period are unchanged.

A future measured orientation profile may apply `target = direction × (source_angle−90) + logical_offset`, with direction +1 or −1. For a sine this becomes `A′=direction×A`, `O′=direction×(O−90)+logical_offset`; leave phase unchanged. Do not also add 180° phase when using signed amplitude or the reversal is applied twice. Logical trim must not duplicate pulse calibration or OTTO EEPROM trim.

The source reverses S2 on its own assembly. No inspected Pi0 hardware evidence establishes that GPIO27 needs the same reversal, so both current pack and nominal examples omit it. Current HAL selects pins from core config, while actual driver calibration is separately loaded from `servo.json`. Missing driver calibration can have flat 1500/1500/1500 endpoints; validate an approved profile rather than assuming core defaults reach the motors. Validate the full angle envelope against configured bounds and measured clearance. Existing `set_angle` clamps pulse conversion but caches the requested angle, so prevalidation is necessary to avoid treating an out-of-range request as the achieved state.

## 6. Worked OTTO translations

### Run forward: preserve a 550 ms clock

Source `run(0)` uses eight amplitudes of 15°, offsets `[105,75,90,90,75,105,90,90]`, and phases `[0,0,90,90,180,180,90,90]` in S0…S7 order. The new action could be:

```json
{
  "kind": "oscillate",
  "run_for_ms": 550,
  "joints": {
    "20": {"amplitude_deg": 15, "offset_deg": 15, "phase_deg": 180, "period_ms": 550},
    "21": {"amplitude_deg": 15, "offset_deg": -15, "phase_deg": 180, "period_ms": 550},
    "22": {"amplitude_deg": 15, "offset_deg": 0, "phase_deg": 90, "period_ms": 550},
    "23": {"amplitude_deg": 15, "offset_deg": 0, "phase_deg": 90, "period_ms": 550},
    "24": {"amplitude_deg": 15, "offset_deg": -15, "phase_deg": 0, "period_ms": 550},
    "25": {"amplitude_deg": 15, "offset_deg": 15, "phase_deg": 0, "period_ms": 550},
    "26": {"amplitude_deg": 15, "offset_deg": 0, "phase_deg": 90, "period_ms": 550},
    "27": {"amplitude_deg": 15, "offset_deg": 0, "phase_deg": 90, "period_ms": 550}
  }
}
```

For GPIO25 the target is 15° at t=0, 30° at 137.5 ms, 15° at 275 ms, 0° at 412.5 ms and 15° at 550 ms. GPIO20 has the opposite hip phase. A validated approach to the complete t=0 pose precedes this clock; it is not included in those timestamps. Backward run swaps hip phases as recorded in the current generator. Choosing one finite cycle is deliberate new completion semantics: OTTO's `execute()` ignores its steps argument and keeps oscillators active while refreshed.

The existing pack stores 37 sampled poses and executes them at M. It preserves this nominal path order but not these timestamps. Increasing samples cannot fix that timing mismatch.

### Walk: preserve twice-frequency feet

Source forward walk uses 550 ms hip periods and 275 ms foot periods, not one uniform period. Its complete nominal transformed parameters are:

| GPIO | Amplitude° | Offset° | Phase° | Period ms |
|---|---:|---:|---:|---:|
| 20 | 15 | 20 | 90 | 550 |
| 21 | 15 | −20 | 90 | 550 |
| 22 | 20 | 10 | 270 | 275 |
| 23 | 20 | −10 | 90 | 275 |
| 24 | 15 | −20 | 270 | 550 |
| 25 | 15 | 20 | 270 | 550 |
| 26 | 20 | −10 | 90 | 275 |
| 27 | 20 | 10 | 270 | 275 |

A 550 ms action completes one hip and two foot cycles. The source's apparent diagonal selection is not a held-opposite-diagonal gait: `pause(1)` refreshes all oscillators. Do not add a diagonal hold based only on that branch. Default limit policy would reject the source timing under the hypothetical 360°/s ceiling above; a common stretch preserves the 2:1 frequency ratio.

### Push-up and wave hand: signed amplitudes matter

For pushUp, GPIO27 has A=40°, O=0°, phase0°, T=5000 ms; GPIO26 has A=40°, O=0°, phase180°, T=5000 ms. The other constant targets are GPIO25=0, GPIO24=0, GPIO21=−65, GPIO20=65, GPIO23=0, GPIO22=0. Include those six A=0 rows to establish the source support pose, rather than inheriting arbitrary prior hip positions.

For waveHAND, GPIO27 has **A=−20°**, O=−60°, phase0°, T=700 ms. Its targets are −60, −80, −60, −40, −60 at quarter-cycle landmarks. Other targets are GPIO25=0, GPIO24=0, GPIO26=−30, GPIO21=−65, GPIO20=85, GPIO23=0, GPIO22=0. Converting amplitude to +20 without a phase change reverses the waveform. These large constant hip offsets still need clearance validation.

### Jump and scared: separate transition time from dwell

The source issues a fast pose command, waits, issues the next pose, waits, then commands home. Nominal transformed vectors in GPIO20…27 order:

| Pose | 20 | 21 | 22 | 23 | 24 | 25 | 26 | 27 |
|---|---:|---:|---:|---:|---:|---:|---:|---:|
| Sit | −20 | 20 | −60 | 60 | −15 | 15 | 60 | −60 |
| Stretch | 60 | −60 | 80 | −80 | −20 | 20 | −80 | 80 |
| Home | 20 | −20 | 0 | 0 | −20 | 20 | 0 | 0 |

Jump is Sit → source pause1000 ms → Stretch → source pause100 ms → Home. Scared is Stretch → source pause2000 ms → Sit → source pause100 ms → Home. The source helper's short branch writes targets immediately; its 1 ms argument is not evidence of physical movement taking 1 ms.

For a first safe software design, use validated positive-duration `pose` actions followed by `dwell` actions with those source pause lengths. Total runtime then includes added transition durations and differs from OTTO. Those transition durations must be calculated from the profile and current pose, not invented as source values. Literal command-then-pause semantics would need the separately gated `pose_write` proposal. The current waypoint pack has the three poses only and cannot reproduce either set of waits.

### Hello: choose intent explicitly

Source hello cannot be faithfully described as a tidy sit/rise/wave timeline. Its long `moveServos()` branch repeatedly starts from local 90° without advancing state, and passes a timestamp-like value as a pause duration. Old/new oscillators may overwrite those commands. With zero source trim, the 150 ms helper repeatedly commands `90+(target−90)/15`; the 500 ms helper repeatedly commands `90+(target−90)/50`. Its waveform has T=350 ms; S1 has O=40°, A=50°, so the nominal source range reaches −10° and output clipping occurs.

The implemented pack records two representative small-helper target vectors followed by one clipped wave cycle, clearly labeled partial. A future controller should default to rejecting its unbounded-angle analytic wave. Options requiring a development decision are: preserve a named legacy-clipped command waveform while accepting corners and timing limits, or create a separately named corrected hello with deliberate sit/rise durations and measured support limits. Do not silently replace hello with intended endpoints and claim exact source fidelity. Literal bug/uptime emulation offers little educational value and is not recommended as the default.

### Remaining inventory

TurnL/TurnR, dance, frontBack, upDown and moonwalkL map by the same amplitude/offset/phase rule, retaining their source periods. Home and hide become explicit poses. OmniWalk must retain the turn-factor formula; its factor-2 true/false defaults are equal modulo whole phase cycles, so distinct labels do not imply distinct paths. The current generator is a traceable parameter inventory, not a future API implementation. See the complete coverage table and selected serial/API defaults in [SpiderBuildinMovements.md](SpiderBuildinMovements.md#5-complete-built-in-movement-library).

## 7. Development phases and acceptance criteria

| Phase | Deliverable | Required evidence |
|---|---|---|
| 1: offline model | Strict separate schema, calibrated-profile validation, compiler and analytic sampler; no hardware imports | Golden source parameter landmarks, mapping and invalid-input tests |
| 2: deterministic runner | Injectable clock/output, shared deadlines, cancellation and ownership interface | Fake-clock tests for phase, durations, pauses, late ticks and stop races |
| 3: isolated opt-in output | Adapter to calibrated servo commands, no default startup activation | Mock backend limits/errors, all command writers inventoried; no automatic resource acquisition on import |
| 4: integration proposal | Separate registry and explicit dispatch, preserving legacy requests | Review all native/Blockly/web/shutdown transitions; regression tests showing unchanged old JSON behavior |
| 5: controlled Pi validation | Measured direction/limits, pulse cadence, jitter, stop latency, power and balance | Owner readiness, supported-body tests first, then limited low-amplitude cycles; no testing has occurred yet |

Meaningful tests should include: all eight GPIO identities with shuffled backend ordering; negative amplitudes and non-cardinal phases; T/2 feet; phase at t=0 and final boundary; entry transition excluded from oscillator runtime; zero-amplitude support poses; repeat boundaries without duplicate dwell; no writes after cancellation including stop between actions; cancellation during dwell and halfway through a frame; stale owner blocked; deadline overrun policy; no post-fault home command; unknown/missing pins and absent/flat calibration rejected; finite numbers and positive periods; limits after transformation; velocity feasibility and common stretch factor; serialization/version errors; no existing config reinterpretation. Use constant-memory evaluation for long runs.

Document whether fractional cycles and continuous mode are supported before adding them. Initial scope should be finite programs only. Attach telemetry for chosen limits, applied time scaling, commanded endpoints, elapsed time, late ticks and termination reason. It is command telemetry, not measured joint feedback.

Hardware gates remain pending: mounting direction, pulse endpoints, travel clearance, supply capacity/common ground, supported-body one-joint tests, multi-joint loading, balance, measured jitter and stop behavior. Existing nominal ±90° and passing host tests do not establish these facts. No dynamics simulation, Pi execution, installation or physical actuation was performed for this proposal.

## 8. Decision and rollback

Proceeding with a separate controller is technically reasonable, with moderate implementation effort and substantial integration/hardware validation work. The reusable pieces are GPIO mapping, logical parameters, calibrated output and the existing opt-in waypoint pack. The principal new work is timing, strict validation, ownership and cancellation—not another list of poses.

Keep the proposed runner behind an explicit opt-in boundary, with no boot-time activation or silent migration. Rollback disables that boundary and removes the separate registry; the old movement controller and configurations continue unchanged. A running worker must first be cancelled and joined under an approved hold/release policy. This design reference is complete as a proposal; its acceptance tests and physical qualifications are future work, not reported successes.

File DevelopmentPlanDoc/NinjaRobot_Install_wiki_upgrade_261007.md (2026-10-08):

# NinjaRobotPi0 installation, onboarding, wiki, and web UI upgrade

Date: 2026-10-07  
Status: **Owner approved; implementation completed on host. Final Raspberry Pi / live-account acceptance and publication remain pending.**  
Scope: installation tooling, interactive onboarding using existing robot tools, web presentation, documentation, wiki relocation, and developer/agent workflow.

## 1. Outcome and approval boundary

Provide a beginner-friendly curl installation entry point for NinjaRobotPi0 and move the embedded wiki from `Wiki/NinjaRobotPi0_Wiki/` to **`ninjarobot_pi0_Wiki/`**, preserving the exact capitalization requested. Align its operating model with NinjaRobotPi5: explicit environment setup, read-only retrieval, traceable current manuals, implementation-to-documentation checks, reviewed semantic updates, and reproducible validation.

Add a resumable terminal onboarding tool that guides the owner through Pi0's existing display, buzzer, servo, and distance-sensor tools, then Google Gemini and ngrok settings. Apply the existing Pi5 web design language to Pi0's Home, Agent, and Help interfaces. The added scope is orchestration and presentation; robot algorithms and control contracts remain unchanged.

The owner subsequently approved implementation with linting and validation. The approved installation, onboarding, wiki and presentation phases are implemented locally. Publication and physical operation remain separate. Existing user reviews are preserved on unchanged pages.

Preserve existing robot backend/driver source, Python package names, CLI commands, configuration formats and locations, GPIO mappings, calibration semantics, and BLE/REST/WebSocket contracts. New onboarding files may call existing tools/helpers after user selection. Pi0 web CSS, presentation markup, accessible labels, and locale copy may change under the newly requested UI scope; existing routes, API payloads, event handling, and robot control behavior must remain compatible. Leave the legacy `NinjaRobotV4` distribution identity and existing V4/V5 backend strings unchanged. No Pi5 files, Education website files, Librarian wiki copies, or Git remote/default-branch settings change in this task.

## 2. Confirmed decisions and scope interpretation

The owner supplied the following decisions after the interrupted planning session. These replace the earlier pending questions. Implementation was subsequently explicitly approved by the owner.

| ID | Decision | Confirmed direction | Implementation boundary |
| --- | --- | --- | --- |
| D1 | Supported device and OS | Raspberry Pi Zero 2 W with Raspberry Pi OS Bookworm 64-bit only | Other targets are rejected until separately qualified |
| D2 | Onboarding | Create an interactive tool similar to Pi5, reusing existing `pi0*` calibration tools and collecting ngrok/Google API settings | Installation remains non-actuating. Hardware tools and live account checks run only after the user selects their onboarding step; no unattended server start, boot autostart, or reboot |
| D3 | Manual authority | Full immutable versioned manuals inside `ninjarobot_pi0_Wiki/`, with short root manual pointers | Preserve existing public manual URLs without maintaining duplicate full manuals |
| D4 | Web UI brand consistency | Apply Pi5's existing UI style to Pi0's web interface | Preserve Pi0 capabilities and React routes; no Pi5-only camera, voice service, pairing protocol, or new movement feature is implied |

Already specified: use `ninjarobot_pi0_Wiki` exactly, retain robot code and Python package names, and prepare a phased plan before implementation. Existing public manual links must continue to follow the repository's default branch. No release tag/version has been requested.

“Google API” refers to the existing Google Gemini key/model workflow already present in Pi0. “Similar to Pi5” means guided terminal steps, clear progress, reuse/retry/exit, and consistent presentation; it does not add Pi5-only providers, camera, microphone hardware, MCP integrations, or its two-wheel calibration assumptions. UI alignment covers style and the organization of existing controls, not a new Game Pad feature. These interpretations satisfy the requested additions while preserving robot functions; no further requirement clarification is currently needed. The owner subsequently approved the revised implementation scope.

## 3. Review baseline and evidence

### 3.1 Repository and review coverage

Pi0 baseline commit: `3dbc41a4ee3cf9fb1019e3be5e633f5a6b47d862`. Pi5 reference commit: `d620fa4e790fd79c1b5d65bc2b95eb71625076cd`.

Pi0 has pre-existing modifications to `.serena/project.yml`, the source catalog, 21 curated wiki pages, and the wiki log. These include the owner's completed semantic review. Pi5 was clean during inspection. The surrounding Education repository contains unrelated changes and is outside the implementation allowlist.

The review inventoried all 610 tracked Pi0 files, all eight robot/root package manifests, both Python lockfile contexts, the frontend manifest/lockfile, agent adapters, wiki configuration/catalog, and test layout. Static AST inspection covered all 125 Python files outside the embedded wiki, including tests and samples, without importing robot modules; the repository contains 157 tracked Python files overall and 28 frontend source files. Focused Serena symbol/body inspection covered installation-sensitive configuration, CLI, HAL, web-server startup, service management, and source-sync behavior. Pi5 bootstrap, installer, wiki launcher, knowledge checker, workflow guidance, and relevant regression tests were inspected as reference implementations.

This is a repository-wide review of installation and wiki integration impact, extended with focused onboarding and UI inspection. Static inventory is not a claim that every robot algorithm has received a fresh functional/security certification. Runtime algorithms remain outside the change scope. No robot server, driver initialization, calibration command, package installation, or physical-device test was executed.

### 3.2 Wiki evidence and actual validation

| Evidence/check | Observed result |
| --- | --- |
| Pi0 `wiki_source_sync.py --check` | All 12 mapped project/source pairs match |
| Pi0 existing wiki `.venv/bin/llmwiki stats` | 21 pages, 14 sources; 21/21 sourced pages have passing semantic reviews |
| Pi0 existing wiki `.venv/bin/llmwiki lint --strict` | 0 errors, 0 warnings, 0 suggestions |
| Pi0 lifecycle/trust | All 21 pages remain `draft` and `unverified`; passing semantic review does not imply human verification or device qualification |
| Pi5 direct wiki search/stats | Installation/workflow pages retrieved; 11/11 sourced pages have passing semantic reviews, with draft/unverified lifecycle/trust |
| Pi5 `python3 scripts/verify_project_knowledge.py` | Pass: manuals, implementation mappings, adapters, and local links |
| Pi5 `python3 scripts/wiki.py search installation` | Blocked by sandbox access to the existing uv cache; used the already-installed wiki CLI directly, without installing dependencies |
| GitHub raw `HEAD` README check | HTTP 200; downloaded README bytes match local Pi0 README. No remote script was executed |
| Robot tests / Pi installation / installer tests | Not run for this plan-only task; the proposed Pi0 installer does not yet exist |
| Safe UI preview | Rendered Pi0 Home/Agent/Help from its tracked `dist` and Pi5 Agent/Game Pad/menu directly from `web_static`, at 390 × 844, using bundled Node Playwright and temporary localhost-only static servers. Backend/API actions were inert and WebSockets replaced with disconnected mocks; no robot backend ran |
| Preview limitations | Pi0's frontend dependencies are not installed locally; its tracked build was inspected alongside current JSX/CSS, not rebuilt. Screenshots establish a visual baseline, not source-build parity, live connectivity, or functional acceptance |

Pi0 primary pages consulted, relative to the old wiki root:

- `wiki/references/installation-and-wiring.md`: setup, pigpio, web build, and old wiki bootstrap location; sources include `src-20260822-installationguide`, `src-20260822-developmentguide`, and both 2026-10-07 migration evidence sources.
- `wiki/overview.md`: package architecture and current knowledge navigation; sources include `src-20260822-readme` and `src-20260822-developmentguide`.
- Related installation boundaries are mapped to `wiki/references/hardware-calibration-and-tools.md`, `wiki/references/api-and-cli-reference.md`, and the package entity pages; those must be checked again against exact changed claims during implementation.

Pi5 references: `ninjarobot_pi5_wiki/wiki/concepts/installation.md`, `wiki/concepts/development-workflow.md`, `wiki/references/installation-guide.md`, `docs/PROJECT_WORKFLOW.md`, and `project-knowledge.json`. Current installation/development evidence includes `src-20260923-installationguide-2`, `src-20260923-developmentguide-2`, and `src-20260907-knowledgeintegration`.

The Education PlatformWiki was queried directly and `wiki/concepts/development-workflow.md` inspected. It is draft/unverified guidance for preserving the separate robot-repository boundary. This Pi0 plan does not change browser contracts and requires no PlatformWiki content update by itself.
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

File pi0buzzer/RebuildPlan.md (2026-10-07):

# pi0buzzer Library — Full Rebuild Plan

> **Version**: 1.0.0 (Full Rewrite)  
> **Status**: ✅ Complete (All 8 Phases Implemented)  
> **Last Updated**: 2026-02-26  
> **Reference**: Old library backed up at `pi0buzzer_bak/`

---

## 1. Health Report of Existing Library (`pi0buzzer_bak`)

### 1.1 File Structure (6 files, ~340 lines total)
```
pi0buzzer_bak/
├── pyproject.toml              # Package config (pigpio, click deps)
├── README.md                   # V5 usage docs
├── LICENSE                     # MIT
└── src/pi0buzzer/
    ├── __init__.py              # Exports: Buzzer, MusicBuzzer
    ├── __main__.py              # CLI: init, beep, playmusic (90 lines)
    └── driver.py                # Buzzer + MusicBuzzer classes (200 lines)
```

### 1.2 Existing API Surface

| Method | Class | Called By (ninja_core) | Behavior |
|---|---|---|---|
| `__init__(pin, pi)` | Buzzer | hal.py | Creates instance, stores pin |
| `initialize()` | Buzzer | hal.py | Starts background worker thread |
| `execute(cmd)` | Buzzer | dispatcher.py, api_wrappers.py | Queues `{frequency, duration}` |
| `play_sound(freq, dur)` | Buzzer | robot_sound.py | Thin wrapper → `execute()` |
| `off()` | Buzzer | hal.py (shutdown) | Stops worker, silences PWM |
| `play_song(song)` | MusicBuzzer | (unused) | Queues note sequence — **blocking** |
| `play_music()` | ⚠️ **MISSING** | __main__.py CLI line 81 | **AttributeError at runtime** |

### 1.3 ninja_core Integration Points

| File | Module Path | Method Used |
|---|---|---|
| `ninja_core/hal.py` | `DRIVER_REGISTRY["buzzer"]` → `pi0buzzer.driver.MusicBuzzer` | `MusicBuzzer(pin, pi)`, `initialize()`, `off()` |
| `ninja_core/robot_sound.py` | `RobotSoundPlayer` | `buzzer.play_sound(freq, dur)` |
| `ninja_core/dispatcher.py` | `_handle_hal_command()` | `buzzer.execute({"frequency": .., "duration": ..})` |
| `ninja_core/api_wrappers.py` | `BuzzerWrapper.tone()` | `buzzer.execute(...)` |
| `ninja_core/api_wrappers.py` | `BuzzerWrapper.play()` | `RobotSoundPlayer.play(emotion)` |
| `ninja_core/config.py` | `BuzzerConfig`, `import_and_update_config()` | Config only — reads `buzzer.json` |

### 1.4 Vulnerability Assessment

#### 🔴 Critical (Blocks Functionality)

| # | Issue | File:Line | Impact |
|---|---|---|---|
| C1 | `play_music()` is undefined | `__main__.py:81` → `MusicBuzzer` | CLI `playmusic` command crashes with `AttributeError` |
| C2 | Blocking `time.sleep()` in `play_song()` | `driver.py:195,199` | Freezes calling thread during song playback |
| C3 | No pause/rest support in queue | `driver.py:189-195` | Pauses use main-thread `sleep` — timing unpredictable |

#### 🟡 Major (Design Flaws)

| # | Issue | Impact |
|---|---|---|
| M1 | Duplicated note dictionaries | `driver.py:168-177` (key format: `"z"`) vs `robot_sound.py:11-35` (key format: `"c4"`) — no single source of truth |
| M2 | No ConfigManager | Raw `json.dump/load` in CLI, no validation, no defaults |
| M3 | No unit tests | Zero test coverage |
| M4 | No async interface | No `async` methods despite ninja_core's asyncio architecture |
| M5 | Hardcoded 50% duty cycle | `driver.py:151` → `set_PWM_dutycycle(pin, 128)`. No volume control |
| M6 | No `info`/`status` CLI | No hardware inspection (unlike pi0disp, pi0vl53l0x) |
| M7 | No interactive tool | No `buzzer-tool` TUI (unlike pi0disp `display-tool`, pi0vl53l0x `sensor-tool`) |

#### 🟢 Minor

| # | Issue | Impact |
|---|---|---|
| m1 | No frequency validation | Accepts any positive frequency |
| m2 | No re-initialization guard | Double `initialize()` starts two worker threads |
| m3 | Per-command `pigpio.pi()` in CLI | Inefficient connection lifecycle |

---

## 2. Compatibility Contract

The rebuilt library **MUST** preserve these exact signatures consumed by `ninja_core`:

```python
# --- hal.py (line 212-215) ---
# DRIVER_REGISTRY["buzzer"] = {"module": "pi0buzzer.driver", "class": "MusicBuzzer"}
from pi0buzzer.driver import MusicBuzzer    # Must resolve
buzzer = MusicBuzzer(pin=17, pi=pigpio.pi())
buzzer.initialize()
buzzer.off()

# --- dispatcher.py (line 162) ---
buzzer.execute({"frequency": 440, "duration": 0.5})

# --- robot_sound.py (line 92) ---
buzzer.play_sound(frequency=440, duration=0.5)
```

> **Note**: `hal.py` imports via `pi0buzzer.driver.MusicBuzzer`. The new library's `pi0buzzer/driver.py`
> must be a compatibility shim that re-exports from the new module path.

---
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

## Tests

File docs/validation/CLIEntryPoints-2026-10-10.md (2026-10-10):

# CLI entry-point repair validation

## 1. Scope of validation

Fix duplicate console-script ownership in root packaging, recreate local provider launchers during installation, and detect all five missing/nonexecutable launchers in read-only setup checks. Robot runtime, drivers, calibration and movement definitions are unchanged.

## 2. Environment and prerequisites

Local Raspberry Pi Zero 2 W/aarch64, Python 3.13.5, uv 0.9.26, existing .venv. Installed root/provider metadata are present; ninja_core, pi0servo, pi0disp, pi0buzzer and pi0vl53l0x launchers are absent. Root and provider RECORD files both claim identical paths. Prior rename transaction logs are unavailable; removal during the rename is the strongest explanation, not a separately logged event. No account/config secrets were printed.

Wiki evidence: installation-guide (draft/unverified, AI review 2026-10-09), registered InstallationGuide src-20261009-installationguide, DevelopmentGuide src-20261009-developmentguide-2 and DevelopmentLog src-20261009-developmentlog-2. CLI retrieval environment was missing, so tracked sources were inspected directly. Existing lifecycle/policy source drift remains owner-deferred.

## 3. Safety notes

No server/device tool is launched by these tests or the repair command. CLI --help and package metadata checks do not initialize HAL. Stop an active robot only in an owner-controlled session with mechanical support/power readiness; shutdown may execute Poweroff. Do not automatically stop pigpiod, run apt, recreate .venv or delete configuration to fix missing launchers.

## 4. Safe smoke tests

```bash
uv lock --offline --check
./install.sh --dry-run
bash -n scripts/install-rpi.sh
PYTHONDONTWRITEBYTECODE=1 .venv/bin/python -B -m pytest -q tests/test_cli_entrypoints.py tests/test_installer_bootstrap.py tests/test_upgrade_workflows.py -k 'not protected_robot_sources_unchanged'
```

Expected: root has no duplicated scripts, each provider retains its command, all launcher checks fail clearly when files are missing and installer fixtures force locked provider reinstallation. The isolated uv venv test creates an unseeded temporary environment only, preserving an inert launcher without installing packages or touching the real environment.

## 5. Communication/interface tests

After the fix is available in the checkout and environment repair is authorized:

```bash
env -u UV_PROJECT_ENVIRONMENT -u UV_PROJECT uv sync --locked --inexact --no-dev \
  --reinstall-package ninja-core --reinstall-package pi0servo \
  --reinstall-package pi0disp --reinstall-package pi0buzzer \
  --reinstall-package pi0vl53l0x
uv run --no-sync ninja_core --help
./install.sh --check
```

This is a real local Python installation/repair, not a diagnostic. It also rebuilds changed root metadata; locked third-party dependency versions stay unchanged. --inexact retains extra/development packages. If uv is private, use the compatible private uv path rather than installing another copy. Run from the project root; wrong directories/environment overrides can select another environment. Normal uv run may synchronize packages; --no-sync explicitly uses the repaired environment.

## 6. Sensor/display checks

Not applicable to launcher repair; no driver change. Actual LCD/QR/sensor acceptance remains separate and pending. No screen or GPIO was activated.

## 7. Actuator-moving or power-risk tests

Server startup is pending owner readiness, not performed here. Once CLI help/setup checks succeed and wiring/calibration/power are ready, the owner may run `.venv/bin/ninja_core server` or `uv run --no-sync ninja_core server`. Startup can energize/center servos, operate display/buzzer and open ngrok; stopping may command Poweroff.

## 8. Expected outcomes

Five existing command names remain available from their packages; root rebuild/uninstall no longer owns/removes those files. Targeted reinstall restores missing launchers even when provider metadata already exists. Environment inspection checks all five paths, never runs a hardware tool and suggests minimal recovery alongside full installation for missing dependencies/interpreter.

## 9. Execution status and evidence

Reproduced ENOENT with `uv run --no-sync -- ninja_core --help` (exit 2). Python module help `.venv/bin/python -B -m ninja_core --help` passed (exit 0), proving code imports without the missing launcher and without starting hardware. 105 focused tests passed, one unchanged-source-baseline test deliberately excluded (exit 0). Full root regression: **331 passed, 1 deselected, 31 existing dbus_next deprecation warnings, exit 0** (88.52 seconds). Focused Ruff, shell syntax, offline lock check and installer dry-run passed. Locked offline repair dry-run plans only six local builds/reinstallations (root plus five providers), no third-party version changes.

Local environment repair and repaired-console help have not been executed without owner approval. No dependency installation in the real environment, server startup, service stop or hardware operation is claimed. Original protected/source fingerprints were not refreshed. Wiki check still reports deferred lifecycle/policy drift plus new repair changes; ingestion, normalization and semantic reviews are intentionally not run.

Read-only installer inspection correctly reports the five missing launchers. An initial npm version probe exceeded its 20-second timeout on this constrained Pi; a direct retry succeeded (npm 11.19.0, Node v24.21.0). This independent transient probe failure is not the cause of Python ENOENT, and no Node/npm replacement was performed. The environment check cannot pass until the missing launchers are repaired.

## 10. Pass/fail checklist

- Failure reproduction and direct module help: PASS.
- Single-provider ownership, RECORD collision simulation and missing/nonexecutable launcher checks: PASS.
- Installer targeted-reinstall fixtures, uv flag compatibility and rerun behavior: PASS.
- Ruff/shell/offline lock/preview: PASS.
- Real environment repair and console help: PENDING owner approval/execution.
- Protected unchanged-source baseline: remains FAIL for authorized accumulated metadata/runtime changes; no fingerprints updated.
- Wiki registration/ingestion/review gates: DEFERRED to owner.
- Server/actuator/display/ngrok acceptance: NOT RUN.

## 11. Rollback steps

Preserve private configuration/calibration and unrelated local changes. Avoid reverting root metadata to duplicate launcher ownership. If a repair fails, retain its first error and retry only after resolving it; do not delete .venv first. An interrupted packaging transaction can require reinstalling the same local providers again. Revert packaging/installer/diagnostic changes together only after review. Original raw sources/current pointers remain unchanged; new English candidates have no invented source IDs/reviews.

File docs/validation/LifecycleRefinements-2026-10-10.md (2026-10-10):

# Lifecycle refinements validation — 2026-10-10

## 1. Scope of validation

Movement-tool deliberate exit, single-browser web ownership, reconnect QR/display ownership, disconnect/timeout cancellation, delayed action guards, and installer/root-project/environment prompt. Drivers, wiring and calibration are unchanged. `center_all_servos` gains an optional lifecycle abort callback; existing callers without it retain their behavior.

## 2. Environment and prerequisites

Automated checks run on the local Raspberry Pi Zero 2 W/aarch64 using existing Python 3.13.5 `.venv` and frontend dependencies. Tests use inert HAL/driver/display/socket fixtures; no live server or hardware tool was started. Existing pigpiod and owner changes to tracked bytecode were left alone. No dependencies were installed. The active shell may need `deactivate`, then `source .venv/bin/activate` to display the new prompt.

Wiki evidence: `spider-otto-waypoint-library`, `web-interface-design`, `dual-connectivity-and-protocols`, `installation-guide`, `motion-system-and-easing`, `safe-execution-and-blockly-runtime`; complete current manuals from 2026-10-09-builtins (`src-20261009-installationguide`, `src-20261009-developmentguide-2`, `src-20261009-developmentlog-2`). Source status is draft/unverified with recorded AI semantic reviews, including 2026-10-09 movement review; that is not physical acceptance. Baseline wiki knowledge check passed. CLI search/source-status environment was unavailable, so tracked sources were read directly without setup.

## 3. Safety notes

Starting movement-tool/server can center servos. Deliberate option 6 now commands configured Poweroff; Spider's extreme ±90° targets require explicit clearance readiness. Wheel/Humanoid without Poweroff use configured home. HAL shutdown releases PWM; no holding torque is guaranteed. Support the robot, raise wheels, verify calibration and joint direction, use external servo power/common ground, and keep an accessible power cutoff. Closing the browser requests cooperative abort, not an emergency-rated physical stop. No claim is made about instantaneous interruption of a blocking driver call.

## 4. Safe smoke tests

These checks do not start robot devices:

```bash
uv lock --offline --check
./install.sh --dry-run
bash -n scripts/install-rpi.sh
bash -c 'source .venv/bin/activate; test "$VIRTUAL_ENV_PROMPT" = ninjarobotpi0'
node tests/web_session_hook.cjs
PYTHONDONTWRITEBYTECODE=1 .venv/bin/python -B -m pytest -q tests/test_lifecycle_refinements.py tests/test_builtin_movements.py tests/test_runtime_pipeline.py
```

Expected: dependencies remain locked, installation preview names ninjarobotpi0, activation sets the new prompt, and inert exit/session tests pass. `./install.sh` without `--dry-run` is a real installation and was not run.

## 5. Communication/interface tests

Pending owner readiness: start the normal runtime (hardware activation), open the ngrok URL on browser A, then navigate Home → Agent → Help without releasing ownership. Open browser B (separate browser/incognito cookie): it must show busy and must not control any API or distance/events socket. Same-cookie tabs count as one controller; closing one must not restore QR while another remains. Close A's last tab: QR returns and B can connect. Repeat at least five handoffs, including Agent playback/Blockly work. Test browser network loss: after 35 seconds without primary-socket input the controller is released; clients retry every 3 seconds and ping every 10 seconds. Check mobile background/sleep behavior, which can suspend heartbeat timers.

REST routes/payloads are unchanged, but `/api/` now requires the HTML-issued cookie and live `/ws/session`. Inactive requests return 423, shutdown requests 503. Direct diagnostic scripts must follow that session contract. This mechanism is connection ownership, not login/authentication. BLE remains a separate existing protocol; global BLE/web arbitration is not introduced.

## 6. Sensor/display checks

Pending: scan the restored QR from the actual LCD at its native dimensions; confirm it reaches the same running ngrok URL. If ngrok is unavailable, confirm the displayed LAN URL is reachable on the same network. No reachable URL/display means there is no QR to show, but browser ownership must still release. Confirm Blockly completion/late agent responses do not paint idle over the waiting QR. Verify distance/events sockets still function after reconnect. Confirm OS/server shutdown does not repaint QR over the shutdown screen.

## 7. Actuator-moving or power-risk tests

Pending, only after explicit physical readiness: back up private config/calibration, support the robot and launch `.venv/bin/ninja_core movement-tool` (startup moves servos). Choose 6 once. Expected order: permitted Poweroff (or home if absent) → HAL shutdown → configuration save, no subsequent center. Observe power/PWM release separately from actual pose holding. For Spider verify every extreme Poweroff target has clearance before selecting 6. Wheel/Humanoid should center only configured joints. Use inert tests, not wrong-type physical commands, to verify rejection.

During browser playback, close the controller and observe abort latency, no continued sequence or later centering, no collision/stall and QR restoration. Separate servo-only, face-only, sound-only and Blockly interruptions before combined work. Do not assume abort can halt arbitrary uploaded code instantaneously.

## 8. Expected outcomes

Exit pose precedes resource release and survives failure via cleanup/save. Exactly one browser identity controls web APIs; last disconnect releases it after cleanup, while stale callbacks remain invalid even when the same cookie reconnects. Missing/failing display cannot deadlock handoff. QR is square, centered and not stretched; native idle restoration remains suppressed while waiting. Installer reuses `.venv` without `--clear`, sets prompt ninjarobotpi0 and syncs the unchanged dependency versions.

## 9. Execution status and evidence

Executed: 72 movement/session/runtime tests passed (exit 0); 93 installer/upgrade tests passed, one protected-baseline case deliberately deselected (exit 0). Full root regression: **319 passed, 1 deselected, 31 existing dbus_next deprecation warnings, exit 0** (207.44 seconds). Initial installer run had three failures caused by a fixture selecting host Node and bypassing inert systemctl; test isolation was corrected, without changing or stopping services. Focused Ruff, shell syntax, Node hook harness and browser fixture syntax passed. Offline lock validation, installer dry-run and local activation prompt check passed. Frontend `npm run lint` and `npm run build` passed; Vite built 95 modules in 6m45s on the constrained Pi. Tracked production assets were regenerated, replacing the old hashed JavaScript bundle. Documentation links for both public READMEs, plan/report and all eight new raw manual/snapshot/evidence documents passed; old registered manual hashes are unchanged.

Protected source check reports nine changes against its older baseline: root pyproject/lock, core metadata, config, movement CLI/controller, agent, runtime pipeline and web server. Some are from the already-reviewed previous built-in feature. Fingerprints are not refreshed. Wiki knowledge check reports changed/new implementation mappings, as expected while new evidence is deliberately un-ingested; current raw originals and pointers are unchanged. Live Playwright is unavailable and was not installed; hook tests are not an actual browser/ngrok test. No servo, display, buzzer or live network service acceptance test occurred.

## 10. Pass/fail checklist

- Inert exit order, errors and type-preserving movement behavior: PASS.
- Inert ownership, tabs, cleanup, timeout, stale-generation/centering guards and QR failures: PASS.
- Inert installer rerun/prompt/lock tests and Node hook checks: PASS.
- Frontend lint/build, documentation links and full root regression excluding unchanged-source baseline: PASS (319 tests).
- Protected unchanged-core gate: FAIL by design; review authorized diffs before updating baseline.
- Wiki ingestion, normalization, curated updates and semantic review: NOT RUN, explicitly deferred to owner.
- Live browser/ngrok reconnect and actual LCD scanability: NOT RUN.
- Physical Poweroff/home, holding behavior, power and abort latency: NOT RUN.

## 11. Rollback steps

Support the robot and isolate actuator power before stopping a runtime, because shutdown may move it. Restore backed-up private config/calibration deliberately. Revert reviewed lifecycle changes together (web backend, session hook/layout, installer metadata) if rolling back: an old frontend without `/ws/session` cannot use the new API guard. Rebuild frontend assets after changing frontend versions. Revert root pyproject and root lock entry together if restoring distribution identity; `.venv` prompt-only activation changes do not alter installed dependencies. Prior immutable wiki raw manuals remain available; new lifecycle sources are candidates and no current pointers were switched.

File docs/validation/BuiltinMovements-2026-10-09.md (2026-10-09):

# Built-in movement validation — 2026-10-09

## 1. Scope of validation

Configuration import/type reconciliation, installed Spider resource, native controller, movement-tool, web movement endpoints/dropdown and Ninja agent text/audio plans. Drivers, wiring and oscillator scheduling were not changed. Wheel/Humanoid have only the owner-confirmed all-servo `home`; Spider has 20 documented entries (566 waypoints including Poweroff).

## 2. Environment and prerequisites

The local environment identifies as Raspberry Pi Zero 2 W Rev 1.0, aarch64. Automated software checks ran here using the existing repository `.venv` (Python 3.13.5), inert/mocked hardware and existing frontend dependencies without installation. Physical Pi acceptance requires the owner-confirmed Spider mapping, valid `servo.json`, known pulse/angle limits and an external servo supply with common ground. HAL obtains channel identities from config calibration keys but physical calibration from `servo.json`; inspect both. Generated fallback calibration is not device acceptance.

Evidence: draft/unverified wiki pages `spider-otto-waypoint-library`, `motion-system-and-easing`, `ninja-core`, `pi0servo`, and `installation-and-wiring`. Source IDs include `src-20261009-2026-10-09-spider-otto`, `src-20261009-developmentguide` and `src-20261008-installationguide-3`. Existing semantic reviews are AI source reviews, not human or physical verification. Wiki search environment was unavailable; tracked sources/pages were read directly. Code corrects historical motion timing/API claims.

## 3. Safety notes

No HAL/device initialization or servo operation was performed in this task. Starting the server or movement-tool can initialize hardware. Server shutdown can execute Spider `Poweroff`, whose ±90° targets are owner-supplied but not clearance-tested. Zero-degree home can move every configured servo and does not establish mechanical safety. Support the body/raise wheels, use known calibration and keep an accessible power cutoff. Do not infer continuous-rotation wheel motor semantics from positional-servo center commands.

## 4. Safe smoke tests

With robot applications stopped, back up private config/calibration outside version control. These commands change configuration only:

```bash
.venv/bin/ninja_core config set-type spider
.venv/bin/ninja_core config import
.venv/bin/python -B -c 'from ninja_core.config import load_config; from ninja_core.builtin_movements import available_movements; c=load_config(); print(c.robot_type, available_movements(c))'
```

Expected: 20 Spider names with all GPIO20–27 configured; reimport preserves edits/custom names. Repeat on separate backed-up configurations with `wheel` and `humanoid`: stored type is `tire`/`humanoid`, and `home` centers exactly the configured pins. Test missing pins and stale wrong-type definitions using inert host tests, not hardware. Never print the full config because it can contain credentials.

## 5. Communication/interface tests

After explicit owner readiness, start the normal runtime; this can energize hardware. Confirm movement-tool option 4, web Agent dropdown and agent capabilities agree for the selected build. The web list is `GET /api/servos/movements`; execute is `POST /api/servos/movements/{name}/execute`. Inert host checks cover 422 rejection before runtime reclamation and 404 missing-name handling. Confirm the page reports an error, not success, when a request is rejected. Restart deliberately after config changes. Test AI rejection with mocked model output before any live account/device test.

## 6. Sensor/display checks

Drivers were not changed. Check face/sound/sensor regression only after normal hardware readiness. Obstacle callbacks now run at waypoint boundaries; the blocking driver does not receive the callback, so immediate interruption inside a single waypoint is not guaranteed. Existing external driver abort and runtime ownership need their own physical acceptance.

## 7. Actuator-moving or power-risk tests

All pending owner validation. First verify one joint at a time at limited travel and confirm the documented GPIO mapping/direction. Then test Wheel/Humanoid `home` or Spider `spider_home` once with the body supported. Only after clearance and power checks test a finite gait cycle. Extreme `Poweroff`, hello, jump and scared require separate explicit readiness; source timing/pauses are not preserved. Do not start with infinite loops or assume a named jump actually jumps safely.

## 8. Expected outcomes

Correct joints respond with calibrated limits, no stall/collision or Pi power reset; type-incompatible movement produces no sequence writes. Import itself produces no hardware activity. Unknown/malformed/partial-channel sequences are rejected before the first step. Driver abort stops later steps without an unsolicited controller centering command. Existing CLI and agent post-task centering remain separate behavior.

## 9. Execution status and evidence

Final software result: **42 feature tests passed** (exit 0), including CLI/web success and rejection, text/audio agent rejection, type switching, reimport, late-step preflight and edited-speed legacy Poweroff. An earlier combined run reported 101 passed, and the original targeted config/Spider/agent run passed 60 tests. These automated checks ran on the Pi with inert drivers. Generator reproducibility, focused Ruff, git diff whitespace checks, frontend lint/build, standalone wheel resource inclusion and loading from the wheel archive passed. No physical motion, hardware acceptance test, dynamics simulation, dependency installation or live AI call occurred.

The earlier full regression run reached 100% with four failures: three installer-bootstrap environment failures due to the existing active pigpiod daemon, and the intentional unchanged-core baseline failure. Full-suite/combined-run Python teardown remained heavily paging after test reporting; those two identified test processes were terminated (exit 143) after their results were captured. The final 42-case feature run exited normally. No daemon/robot process was stopped. The detailed raw evidence records this distinction.

`scripts/verify_core.py` detects six intentional protected changes: core package metadata, config, movement CLI/controller, agent and web server. Baseline fingerprints were not refreshed. Wiki ingestion/review and source mapping updates are deferred at the owner's request; wiki completion is not claimed.

## 10. Pass/fail checklist

- Local configuration/idempotency/legacy/type rejection: PASS, final 42-case feature suite exit 0.
- Full trajectory parity and shuffled GPIO mapping: PASS in inert tests.
- Frontend lint/build and standalone wheel resource smoke: PASS. Full regression run: four failures, followed by terminated teardown; not a clean full-suite pass.
- Protected unchanged-core gate: FAIL by design for six authorized feature changes; review pending.
- Wiki ingestion/strict semantic review/index gates: NOT RUN, deferred to owner.
- Physical mapping, direction, clearance, balance, power, timing and stopping: NOT RUN.

## 11. Rollback steps

Support the robot and disconnect actuator power before stopping an active runtime; shutdown may execute Poweroff. Restore the backed-up private `config.json` and `servo.json` deliberately, then restart only after readiness. To remove imported data manually, remove the named built-ins and their matching metadata; reimport will seed them again. Revert the reviewed feature code as a coordinated change if reverting runtime behavior. Registered old wiki raw originals remain available; new candidate versions have not been ingested.

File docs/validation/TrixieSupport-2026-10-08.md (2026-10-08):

# Trixie installation correction — 2026-10-08

## Scope and root cause

The reported Pi is a Zero 2 W running Debian 13 (Trixie) 64-bit. `install.sh` explicitly
required `VERSION_CODENAME=bookworm`; `scripts/install_check.py` repeated that restriction
for local install, software checks and onboarding. Architecture (`aarch64`) and release
codename are independent checks. The error occurs before cloning, apt, or hardware activity.
It followed the original Bookworm-only requirement; the owner's new request extends the
installer target to Bookworm **or Trixie** on the same hardware and architecture.

Changes: release allowlists/help in bootstrap, local installer and onboarding; actionable
Python preflight diagnostics; release/rejection regressions; Python 3.11/3.13 CI matrix;
current README and immutable manual/wiki versions. Robot packages, GPIO behavior, lockfiles,
tool pins and system Python remain unchanged. No bypass flag or `/etc/os-release` edit is used.

## Environment and dependency evidence

Raspberry Pi's [Trixie announcement](https://www.raspberrypi.com/news/trixie-the-new-version-of-raspberry-pi-os/)
confirms the Raspberry Pi OS release. Debian's [release notes](https://www.debian.org/releases/trixie/release-notes/whats-new.en.html)
list the change from Python 3.11 to 3.13. The existing installer selects `/usr/bin/python3`
and `python3-dev`/`python3-venv`, so Trixie uses its own 3.13 interpreter. Existing locked host
environments exercise both Python versions without changing the robot dependency lock.
This is not a full Debian arm64 OS/package-transaction or physical-device certification.

Wiki evidence: current overview, installation-guide, installation-and-wiring, guided-onboarding,
and development-workflow pages; all are draft/unverified. Their old Bookworm-only statements
are superseded by this user-authorized target expansion; historical raw sources stay immutable.

## Safety and smoke checks on the Pi (pending)

Keep actuator power disconnected during installation. After publishing this fix to the official
default branch, rerun the original curl command. HEAD follows the repository default branch.
If a checkout already exists, update it to the fixed revision and use its local installer;
the bootstrap refuses to overwrite an existing destination. Never delete calibration to retry.

```bash
uname -m                 # aarch64
cat /etc/os-release      # VERSION_CODENAME=trixie (or bookworm)
# After downloading/updating the fixed checkout:
cd "$HOME/NinjaRobotPi0"
./install.sh --dry-run
./install.sh
./install.sh --check
./onboard.sh --dry-run
./onboard.sh --status
```

Expected: Trixie passes the release gate, software installs/checks complete, and read-only
onboarding modes create no default robot settings and activate no hardware.

## Communication, sensor/display and actuator acceptance (pending)

Use the README first-test checklist after software installation. Start pigpiod deliberately,
verify I2C/SPI and use `./onboard.sh` with the robot supported. Display/buzzer/sensor tools
activate their devices. Servo-tool can center servos before its menu; server start can also
move hardware and attempts ngrok. Verify each component, import saved calibration, then test
web/BLE/Google/ngrok with your own accounts. These live checks were not executed on this host.

## Execution status and rollback

Host release tests cover quoted/unquoted Bookworm/Trixie, the reported Debian identity, and
rejection of unknown/old releases, 32-bit architecture, other Pi hardware, root and other OS IDs.
The existing private Git/bootstrap fixtures remain in use. Final host results are appended below.
Python 3.13 emits existing dbus-next deprecation warnings about removal in Python 3.15; it passes
current tests. Future Python releases are not qualified by this change.

There is no OS migration or dependency upgrade to undo. Reverting this patch reinstates the
Bookworm-only gate. Preserve robot settings and stop after any failed install stage; repair and
retry locally. Actual apt/pigpio/arm64 dependency installation, physical tests and remote CI remain
pending. The fix is local until committed/pushed; no remote publication was performed by this task.

## Final host results

- Python 3.11: **184 root tests passed**.
- Python 3.13: **184 root tests passed**, with eight existing dbus-next deprecation warnings.
- Python 3.13 driver suites: **265 passed** (servo 82, display 57, buzzer 65, sensor 61).
- Ruff lint/format, ShellCheck and diff whitespace checks passed.
- Protected core/metadata gate passed; robot package sources and lockfiles unchanged.
- Current manual/code mappings, strict wiki lint, links and indexes passed. Seven relevant pages
  have new source-grounded review records; lifecycle remains draft/unverified.
- No Pi hardware, OS package transaction, live account, GitHub CI run or publication was performed.

On-device next step: publish this correction, rerun the original curl command on the reported
Trixie system, then follow the non-moving software checks before any onboarding hardware action.

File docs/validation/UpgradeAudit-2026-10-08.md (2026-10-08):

# Pi0 installation, onboarding, wiki and UI audit — 2026-10-08

Scope: the approved `DevelopmentPlanDoc/NinjaRobot_Install_wiki_upgrade_261007.md`,
followed by the owner's explicit request to audit/fix new features, align the terminal
onboarding with Pi5 and rewrite the README. No core robot/driver behavior change is authorized.
Pi0 baseline: `3dbc41a4ee3cf9fb1019e3be5e633f5a6b47d862`.
Pi5 reference: `d620fa4e790fd79c1b5d65bc2b95eb71625076cd` (read-only).

## Findings and fixes

| Priority | Finding | Correction and regression evidence |
| --- | --- | --- |
| High | Servo import could prefer conflicting legacy pulse aliases over the fields onboarding validated; signed/noncanonical numeric keys could evade the numeric-key filter | Validate every numeric GPIO key in canonical form and reject conflicting aliases; seven regression cases cover override fields and invalid keys. Existing importer unchanged |
| Medium | Settings helpers could create credential files with a normal process umask before the wrapper restricted permissions | Set owner-only umask around the worker, restrict existing files before writes, restore original mask afterward; test verifies permissions at first write, including exception path |
| Medium | `--resume` repeated hardware setup; saved physical observations could outlive their calibration | Reconcile current saved bytes/hash, invalidate changed observations and skip only unchanged, valid previously completed hardware; status performs the same reconciliation without writing |
| Medium | Malformed saved progress could crash with an attribute error, and arbitrary results were accepted | Bound size, validate schema/step/record types, hardware hashes and status enums before entering write-finally; invalid state stays byte-identical |
| Medium | Hardware setup failure or an invalid menu choice advanced to later steps without recovery | Pi5-style numbered guidance, valid-choice prompts, bulk/per-module reuse, retry-in-place, Enter to continue, and readable summary; tests cover failure→retry→success and bulk reuse |
| Medium | Hidden worker bypassed the supported-platform preflight | All interactive execution now passes the same TTY/platform gate, including internal workers; test proves no helper executes on rejection |
| Medium | Nested private tool paths could redirect writes through symlinks and rejection occurred after privileged package work | Preflight now rejects symlinked ancestors/tool subdirectories/environments before privileged installation; direct regression test |
| Medium | Standalone wiki setup could inherit `UV_PROJECT`, and fresh installer users lacked globally discoverable uv | Clear the project override and fall back to the installer-owned uv executable for explicit setup only; both behaviors tested |
| Low | Read-only tool-version checks accepted arbitrary version prefixes | Exact Node/pigpio matching and exact uv version with optional parenthesized build metadata |
| Low | Failed installation-record publication could leave a partial temporary file | Flush/fsync and finally-cleanup before/after atomic replacement; injected failure test |
| Documentation | Root README lacked a beginner installation/test manual; first-operation guidance assumed global uv and understated runtime ngrok behavior | Rewritten in Pi5-style sections with private-venv commands, default-branch curl, onboarding, test checklist, troubleshooting and multilingual summaries. Runtime start/servo initialization/ngrok attempts clearly separated from onboarding |

Calibration status hashes the exact bytes it validated, preventing a second read from associating
one configuration's validation with another configuration's fingerprint. Software checks still do
not establish correct physical wiring, pulse limits for a particular servo, or actual calibration.

## Plan coverage

| Plan phase | Audit result |
| --- | --- |
| 0 — Baseline | Existing robot packages protected; original user/wiki work preserved |
| 1 — Installer inputs | Existing pinned uv/Node/pigpio manifest, hashes and provenance retained; this audit does not claim new supply-chain attestation |
| 2 — Bootstrap | Existing isolated Git fixtures exercise default branch, explicit refs, ambiguity, destination refusal and checkout behavior |
| 3 — Local installation | Reviewed preflight, locks, apt policy cleanup, checksum failure, environment isolation, inactive services, locked dependencies and recording; added path/version/cleanup fixes |
| 3A — Onboarding | Compared directly with Pi5 `setup_wizard.py`, not its separate web coordinator; corrected guidance/reuse/retry/resume/summary and configuration boundaries |
| 3B — Web interface | Reviewed changed JSX/CSS/locale scope and control payload preservation; lint/build and 64 inert browser assertions pass without changing the bundle |
| 4 — Wiki relocation | Retains populated wiki and original immutable sources; no re-copy from Librarian or Pi5 |
| 5 — Integration | Launcher/checker/agent adapters reviewed; fixed standalone wiki uv discovery and project override isolation |
| 6 — Current knowledge | New complete dated manuals, README snapshot and audit evidence; exact reviewed semantic diffs and source-grounded page reviews; earlier evidence preserved |
| 7 — Validation | Local checks below; physical Pi, live accounts and remote CI remain pending |
| 8 — Publication | No commit, push or deployment; curl publication still pending |

## Pi5 onboarding consistency

Shared flow: branded welcome, ordered hardware steps, explanation/action/status text, saved-setting
reuse across all modules, individual tools, retry, Enter-to-continue, Q/save/exit, resume and summary.
Pi0 keeps display/buzzer/servo/distance and its existing import/identity/Gemini/ngrok settings.
It deliberately retains the approved READY warning for all Pi0 devices, multi-limb servo wording,
independent operator observations and manual server start. Pi5's two-wheel assumptions, extra
hardware/providers/MCP, simulation and launch controls are not imported.

## Local validation

- Python 3.11 locked root environment: 160 tests passed excluding the seven project-knowledge tests pending final document-map update; final combined result recorded below.
- Ruff checks/format, ShellCheck: pass for upgrade tooling/tests.
- Frontend lint/build: pass; isolated source and built output match the workspace exactly.
- Inert Playwright: 64 assertions pass at 360, 390, 844 and 1280 pixel widths; routes, locales, API payloads, WebSockets, focus return and shutdown cancellation checked. No backend/hardware ran.
- Core protection: 120 recorded source/test/metadata/lock files pass; original package-file comparison recorded below.
- Final knowledge/source/review/link/index checks are recorded below after new evidence is applied.

## Remaining acceptance

Run the README's physical checklist on Zero 2 W / Bookworm 64-bit, including fresh install and retry,
real calibration/cancellation, Gemini discovery, ngrok and first server start. No physical or account
operation was performed here. Pi0 retains its existing public-tunnel/control security model; it has
not acquired Pi5 pairing/authentication. Server start may move hardware and attempts ngrok; skipping
onboarding's token step does not promise offline isolation. These existing runtime boundaries were
documented without modifying core code.

Shell fixtures and host tests do not prove an OS package transaction, pigpio C build or npm build
will fit every microSD/RAM/network condition on a real Pi. GitHub CI and published curl acceptance
require publication and are not claimed as executed.

## Final audit gate results

- **168 root tests passed** on Python 3.11, including 20 added audit regressions. The final run includes cancellation after calibration changes; observations are reconciled before saving even when the operator interrupts the verification prompt.
- **61 wiki tests passed** in the independent wiki environment.
- **64 inert browser assertions passed**; frontend lint/build passed and output is byte-identical to the checked workspace bundle.
- **Ruff lint/format, ShellCheck, and diff whitespace checks passed.**
- **Knowledge check, strict wiki lint, links and indexes passed:** zero errors, warnings or suggestions; 26/26 sourced pages have current passing AI semantic reviews and remain draft/unverified. Three historical pending source versions are preserved; all five newly registered audit/manual/README sources were ingested.
- **323 original tracked robot package files are byte-identical** to the captured pre-upgrade baseline. The 120-file protected core/metadata gate also passes. All 18 original raw evidence files retain their bytes after relocation. Pi5 remains clean and unchanged.
- No robot service, hardware tool, live account or public tunnel was started during this audit. No Git commit or push was made.

The earlier local-validation paragraph records the intermediate checkpoint copied into immutable
raw audit evidence. These final results supersede its pending combined-test and knowledge-gate notes.

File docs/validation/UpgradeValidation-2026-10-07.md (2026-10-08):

# Pi0 upgrade validation and real-device handoff

## 1. Scope of validation

Installer/default-branch bootstrap, guided onboarding, embedded wiki/manual workflow, and
Pi5-derived Pi0 web presentation. Robot algorithms, drivers, Python identity, GPIO mappings
and transport contracts remain unchanged. `core_baseline.json` records 120 protected source,
test, metadata and lock inputs against Pi0 commit `3dbc41a4ee3cf9fb1019e3be5e633f5a6b47d862`.
Pi5 reference commit: `d620fa4e790fd79c1b5d65bc2b95eb71625076cd`; Pi5 remains read-only.

## 2. Environment and prerequisites

Executed on macOS with isolated locked Python 3.11.15 and 3.13.14 environments, Node 24.18.0,
existing frontend lock (Vite 7.3.0), ShellCheck 0.11.0 via shellcheck-py 0.11.0.1, and Chromium
via Playwright 1.62.1. Installer pins are uv 0.11.29, Node 22.23.3 Linux arm64 and pigpio v79
commit c33738a320a3e28824af7807edafda440952c05d. Host build is not ARM resource qualification. Installation clears unrelated developer environment
overrides and explicitly includes frontend build dependencies even with NODE_ENV=production.
CI uses Python 3.11 and pinned Node 22.23.3; its remote run remains pending publication.

Manual acceptance target: Raspberry Pi Zero 2 W, Raspberry Pi OS Bookworm 64-bit, normal user
with deliberate sudo authorization, sufficient disk space/network and unchanged saved configs.
Full source-version manuals are linked by the wiki README and project-knowledge.json.

## 3. Safety notes

Disconnect actuator power for software installation. Installation never activates pigpiod,
calibration, robot server, boot autostart or reboot. Standalone tools and server initialization
can activate devices immediately; servo-tool can center saved servos before its menu.
Support limbs/wheels, clear travel and keep power removal available before typing READY.
Software-valid saved calibration is not physical verification. Stop any existing robot server
before standalone tools. Review wiring against the current manual before activating GPIO.
No real hardware, remote tunnel or account was used in the host checks.
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

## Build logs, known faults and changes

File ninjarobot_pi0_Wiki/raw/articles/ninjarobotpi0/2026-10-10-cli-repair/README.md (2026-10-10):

# NinjaRobotPi0

# English

## 1. What Is NinjaRobotPi0?

**NinjaRobotPi0** is an open-source, modular educational robot built on the **Raspberry Pi Zero 2 W** (a tiny, affordable computer about the size of a stick of gum). It brings together servo motors (for movement), an LCD display (the robot's face), a buzzer (for sounds and melodies), a distance sensor, Google Gemini AI chat, Bluetooth Low Energy (BLE), and a browser-based control interface — all in one compact package.

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

### What can it do?

- **Move and express itself** — Use the built-in movement library to make your robot walk, wave, or dance. The LCD face shows animated expressions, and the buzzer plays emotion sounds.
- **Sense distance** — A VL53L0X laser sensor measures distances in millimetres, so your robot can detect obstacles.
- **Chat with AI** — Connect a Google Gemini API key and let the AI chat with you. The AI can even trigger robot actions like movements and expressions.
- **Control from your phone** — Open a web browser on any device and you get a control panel with Home, Agent (AI chat), and Help pages — in English, Japanese, Traditional Chinese, and Simplified Chinese.
- **Learn step by step** — Calibrate each component with guided tools, then explore the Python packages and web interface at your own pace.

### Who is this for?

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

---

## 2. Quick Start Guide

Follow these steps to build and run your own NinjaRobotPi0 from scratch.

### 2.1 Recommended Hardware

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

> **📎 Full hardware details:** See the [Installation Guide](../2026-10-09-builtins/InstallationGuide.md)

### 2.2 Hardware Wiring

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

#### Pin Connections

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

```
┌─────────────────────────────────────────┐
│         Raspberry Pi Zero 2 W           │
│                                         │
│  GPIO 20–27 ─────── Servo signals (×8)  │
│  GPIO 10,11,8 ────── ST7789V SPI data   │
│  GPIO 14,15,16 ───── ST7789V control    │
│  GPIO 2,3 ─────────── VL53L0X I2C      │
│  GPIO 17 ──────────── Buzzer signal     │
│  GND ──────────────── Common ground     │
└─────────────────────────────────────────┘
            │                    │
     Pi 5V micro-USB     Separate 5V supply
     (Pi power only)     (servo power only)
                    ↕ shared GND ↕
```

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

### 2.3 Raspberry Pi OS Installation

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

   ```bash
   ssh YOUR_USERNAME@ninjarobotpi0.local
   ```

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

8. Enable the hardware interfaces your components need:

   ```bash
   sudo raspi-config
   ```

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

   Reboot when prompted:

   ```bash
   sudo reboot
   ```

9. After reboot, verify your setup:

   ```bash
   uname -m                         # Should show: aarch64
   cat /etc/os-release              # Inspect OS identity; Bookworm/Trixie are reference releases
   ```

### 2.4 Project Installation

#### Default installation (recommended)

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

```bash
curl -fsSL https://raw.githubusercontent.com/NinjaRoboticsEducation/NinjaRobotPi0/HEAD/install.sh | bash
```

When prompted, read the installation plan and type `INSTALL` to confirm. The installer will:

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

#### Custom folder installation (alternative)

If you want to install into a different location (e.g., `~/Projects/NinjaRobotPi0`):

```bash
mkdir -p "$HOME/Projects"
curl -fsSL https://raw.githubusercontent.com/NinjaRoboticsEducation/NinjaRobotPi0/HEAD/install.sh | bash -s -- --install-dir "$HOME/Projects/NinjaRobotPi0"
```

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

#### After installation

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

```bash
cd "$HOME/NinjaRobotPi0" &&
./install.sh --check &&

# Start pigpio now:
sudo systemctl start pigpiod

# Optional: make pigpio start automatically on future boots:
sudo systemctl enable pigpiod
```

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

### 2.5 Onboarding — Set Up Your Robot

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

Start the wizard:

```bash
./onboard.sh
```

The wizard walks you through these steps in order:

| Step | What you do | How you know it worked |
|---|---|---|
| **1. Display** | Enter your display's actual GPIO pins, set orientation and brightness | You see a test image on the LCD screen |
| **2. Buzzer** | Confirm the buzzer pin and play a test tone | You hear a short beep, then silence |
| **3. Servo** | Type `READY` only after supporting the robot; calibrate each servo's range and neutral point | Each servo moves to its expected position |
| **4. Distance** | Read sensor values, then calibrate at a known distance | Readings match the real distance |
| **5. Import** | Import display, buzzer, and servo settings into the main `config.json` | All settings pass validation |
| **6. Identity** | Set a BLE name and choose your robot type: `tire`, `humanoid`, or `spider` | Name and type match your build |
| **7. Gemini** | Enter your Google Gemini API key (hidden input), choose an AI model | Model validates successfully (internet required) |
| **8. ngrok** | Optionally enter your ngrok authtoken for remote access | Token is saved (no tunnel opens yet) |

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

**Useful onboarding commands:**

```bash
./onboard.sh --dry-run         # Preview without changing anything
./onboard.sh --status          # Check current progress and file validity
./onboard.sh --resume          # Resume from where you left off
./onboard.sh --step servo      # Jump to a specific step
./onboard.sh --step gemini     # Change your API key or model
./onboard.sh --step ngrok      # Configure remote access token
```

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

### 2.6 Create Robot Movements

Use the `movement-tool` to create custom movement sequences (walking patterns, dance moves, gestures):

```bash
.venv/bin/ninja_core movement-tool
```

The movement tool lets you:

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

**Movement command format:**

```
[SPEED_]PIN:ANGLE[SPEED][/PIN:ANGLE[SPEED]...]
```

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

### 2.7 Start the Server and Use the Web Interface

Keep the robot supported for the first start. From the project root:

```bash
.venv/bin/ninja_core server
```

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

#### Open the web interface

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

The web interface has three pages:

| Page | What it does |
|---|---|
| **Home** | Robot entry page with a power-off slider control |
| **Agent** | AI chat with Gemini, expressions, sounds, movements, and distance readings |
| **Help** | Usage guidance; the menu also lets you switch the interface language |

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

---

### 2.8. Automatic Startup (Optional)

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

#### Step1: Install the Startup Service

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

```bash
NINJAROBOT_UV="$(python3 -B scripts/install_check.py --find-tool uv)" &&
PATH="$(dirname -- "$NINJAROBOT_UV"):$PATH" .venv/bin/ninja_utils install-startup
```

This will:

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

#### Step2: Verify

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

```bash
.venv/bin/ninja_utils status-startup
```

#### Step3: Reboot

Reboot your Raspberry Pi:

```bash
sudo reboot
```

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

#### Removing Autostart

If you want to stop the robot from starting automatically:

```bash
.venv/bin/ninja_utils remove-startup
```

---

## 3. NinjaRobotPi0 File Structure

```
NinjaRobotPi0/
├── ninja_core/               # Central server: HAL, motion, AI agent, web server
├── ninja_ble/                # Bluetooth Low Energy GATT service
├── ninja_utils/              # Shared interfaces, logging, and system utilities
├── ninja_webapp/             # React + Vite frontend (browser control interface)
├── pi0servo/                 # Servo motor driver (velocity-based, up to 8 servos)
├── pi0disp/                  # ST7789V LCD display driver (face expressions)
├── pi0buzzer/                # Passive buzzer driver (sounds and melodies)
├── pi0vl53l0x/               # VL53L0X distance sensor driver
├── ninjarobot_pi0_Wiki/      # Built-in project knowledge base
├── scripts/                  # Installation and maintenance scripts
├── tests/                    # Automated test suite
├── docs/                     # Validation reports and documentation
├── 3Dmodels/                 # 3D-printable robot chassis models
├── assets/                   # Static resources (images, etc.)
├── config.json               # Robot configuration (identity, hardware, Gemini key)
├── servo.json                # Servo calibration data
├── install.sh                # One-command installer
├── onboard.sh                # Guided setup wizard entry point
├── pyproject.toml            # Python project metadata and dependencies
└── README.md                 # This file
```

---

### Built-in movements by robot type

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

```bash
.venv/bin/ninja_core config set-type spider  # Or wheel / humanoid; wheel is saved as tire
.venv/bin/ninja_core config import
```

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

### Exit, reconnect and environment prompt

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

## 4. Troubleshooting

### `uv run` cannot spawn `ninja_core` after upgrading

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

```bash
cd /home/rogerchang/NinjaRobotPi0  # Use your actual checkout path
env -u UV_PROJECT_ENVIRONMENT -u UV_PROJECT uv sync --locked --inexact --no-dev \
  --reinstall-package ninja-core --reinstall-package pi0servo \
  --reinstall-package pi0disp --reinstall-package pi0buzzer \
  --reinstall-package pi0vl53l0x
uv run --no-sync ninja_core --help
./install.sh --check
```

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

### Installation stopped before Python setup

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

```bash
sudo systemctl stop ninjarobot   # Only if this service is installed/running
sudo systemctl stop pigpiod
cd "$HOME/NinjaRobotPi0" && ./install.sh && ./install.sh --check
```

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

### Installation Issues

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

### Hardware Issues

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

### Server / AI Issues

| Problem | Solution |
|---|---|
| Gemini setup fails | Check your internet connection and API key. Retry with: `./onboard.sh --step gemini` |
| ngrok setup fails | Check your internet connection and authtoken. Retry with: `./onboard.sh --step ngrok` |
| Server starts but web page is unreachable | Make sure your phone/computer is on the same Wi-Fi network as the Pi. Try using the Pi's IP address directly. |

---

## 5. Appendix

### Appendix A: Google Gemini API Key

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

#### Step 1 — Open Google AI Studio

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

#### Step 2 — Create an API key

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

#### Step 3 — Save the key on your Pi

During onboarding, the wizard will ask for your Gemini API key at the **Gemini** step. Paste it in — the input is hidden for security. The wizard then lets you choose from the available AI models associated with your key.

If you already completed onboarding and want to change the key:

```bash
./onboard.sh --step gemini
```

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

### Appendix B: ngrok Account Setup

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

#### Step 1 — Create an ngrok account

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

#### Step 2 — Save the token on your Pi

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

If you already completed onboarding and want to add or change the token:

```bash
./onboard.sh --step ngrok
```

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

---

### Appendix C: Compatibility and reference checks

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

Full references: [Installation Guide](../2026-10-09-builtins/InstallationGuide.md), [Development Guide](../2026-10-09-builtins/DevelopmentGuide.md), [Development Log](../../../notes/ninjarobotpi0/2026-10-09-builtins/DevelopmentLog.md).

## License

NinjaRobotPi0 source code is licensed under the [MIT License](../../../../../LICENSE).

<div align="center">

Made with ❤️ for AI Robotics Education

</div>

---
---

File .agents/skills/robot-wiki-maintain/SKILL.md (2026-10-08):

---
name: robot-wiki-maintain
description: Keeps the NinjaRobotPi0 local wiki aligned after features, APIs, setup, architecture, hardware guidance, or project documents change. Use to create immutable project-owned source versions, normalize new sources, prepare reviewed wiki plans, and run wiki quality gates; do not use for read-only questions.
---

# NinjaRobot Wiki Maintenance

Full manuals live as immutable dated versions under `ninjarobot_pi0_Wiki/raw/`.
Read the nested AGENTS and matching `wiki-*` skill. Resolve current versions using
`project-knowledge.json`; create a NEW complete dated source rather than overwriting one.
Rebase links, register/normalize new evidence explicitly, and preserve original hashes/history.
Create a schema-v2 plan with current source/target hashes, validate it and show its exact diff.
Apply only when the owner's approval covers that diff/scope; the approved implementation plan
already covers its named page updates. Expanded scope needs new approval.
Review changed sourced pages one by one and report actual checks; never invent human verification.
Update current README/root-pointer links and reviewed implementation mappings.
Run `python3 scripts/wiki.py check`, `lint --strict`, `link check`, `index check`, and `stats`.
Do not blindly refresh fingerprints or old review hashes. Queries have no setup/sync side effects.
Legacy `wiki_source_sync.py --sync` is retired; --check delegates to the new knowledge gate.
Robot functions and hardware are never modified/activated as a wiki-maintenance side effect.

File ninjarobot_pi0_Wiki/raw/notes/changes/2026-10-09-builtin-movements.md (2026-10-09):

# Automatic native built-in movement evidence — 2026-10-09

Candidate raw evidence only. The owner requested implementation and raw updates, and explicitly deferred wiki ingestion/review until manual validation. No source registration, normalization, semantic-plan application, curated-page change, current-pointer update, source-map refresh or semantic/human review was performed.

## Requested and implemented behavior

- Module config import seeds the selected profile after subsystem settings are collected. Robot type changes reconcile using existing configured channels. Existing config loads remain read-only.
- Spider receives the proposal's exact 19 `spider_*` trajectories and `Poweroff` (20 entries, 566 steps) when all BCM GPIO20–27 are configured. The original repository `spider_otto_*` pack/generator remain unchanged; an installed package resource contains equivalent trajectory data.
- Owner clarification: Wheel and Humanoid receive only a movement named `home`, commanding all configured servos to 0° at Slow speed. Other default gaits will be implemented by the owner later. Wheel input normalizes to the existing stored `tire` value.
- Additive `movement_robot_types` metadata scopes imported movements; `builtin_movement_hashes` preserves edits/custom collisions during reimport/type/channel changes. Only unchanged managed values are automatically removed/replaced. Incompatible edited entries remain stored but are not runnable on the new type.
- CLI execute option 4, existing web dropdown/list API and Ninja agent use shared compatible discovery. Controller execution preflights every waypoint against known type scope and active channels before the first servo write. Known prefixes and copied/renamed known Spider pose sequences, including legacy Poweroff with changed speeds/omitted empty overrides, remain guarded without metadata.
- Validate nonempty supported steps, canonical GPIO keys within BCM0–27, available channels, finite nominal ±90 angles, F/M/S speeds and valid overrides. A malformed later step prevents the entire movement from starting.
- Controller lock serializes its own operations. Callback checks occur before/after blocking driver steps; driver abort stops sequence advancement without an unsolicited controller recovery pose. In-step callback interruption and independent driver writers remain limitations.
- Web GET/POST routes and payloads stay compatible: `/api/servos/movements` returns `{"movements": [...]}`; `/api/servos/movements/{name}/execute` returns 404 unknown, 422 invalid/incompatible before runtime reclamation, 409 abort. Frontend logs HTTP errors and encodes movement names; rebuilt generated assets replace the old JS bundle.
- Text/audio agent plans use exact permitted names and configured type. Reject entire invalid native chains while retaining the response/logging the reason. Limits: 32 chain entries, 1–20 positive integer repetitions per entry. Saved Blockly actions remain separate.

## Code, documentation and validation scope

Code: `ninja_core/src/ninja_core/builtin_movements.py`, installed `data/spider_otto.json`, config, movement_controller, movement_cli, ninja_agent, web_server and core package build metadata; frontend Agent page and generated dist. No driver, original Spider pack/generator, live config/calibration, service or hardware setting was changed.

Documentation: root README/core README; `docs/BuiltinMovementsImplementationPlan.md`; `docs/validation/BuiltinMovements-2026-10-09.md`; complete new dated raw manuals, README snapshots and plan snapshot. English, Japanese and Traditional Chinese summaries cover import, home scope and physical readiness; detailed new design/testing sections remain English.

The local environment identifies as **Raspberry Pi Zero 2 W Rev 1.0**, aarch64, existing Python 3.13.5 environment. Tests used inert/mocked hardware and synthetic configuration files. No HAL initialization, servo/GPIO/buzzer/display activation, package installation or live AI/account request was performed. Existing pigpiod was left running and untouched. Physical direction, mapping, clearance, balance, power, timing and stopping acceptance remain pending.

## Verification results

- Initial 39 new feature tests and 60 existing config/Spider/agent regressions passed.
- After the owner-confirmed home naming and CLI/web success tests, the combined targeted run reported **101 passed**.
- The final feature suite reported **42 passed in 284.93s**, exited normally (0), and includes the legacy-Poweroff pose-recognition regression.
- The broader earlier suite reached 100% with four failures: three installer-bootstrap cases failed because the existing pigpiod daemon was active; `test_protected_robot_sources_unchanged` detected six authorized feature changes. Installer tests used mocks and did not perform installation. These failures do not establish movement regression; they are retained for owner review, not suppressed or fixed outside scope.
- Focused Ruff and `git diff --check` passed. Frontend `npm run lint` and `npm run build` passed (94 modules, generated new JS bundle).
- `python3 scripts/build_spider_movements.py --check` passed: original 19-entry pack is byte-for-byte reproducible. Feature tests compare all 20 JSON fragments in the supplied proposal with the runtime catalog, preserving trajectory values and exact Poweroff.
- Built a standalone core wheel using existing cached Hatchling dependencies without installing anything. Its archive contains the Spider JSON resource; the catalog loads 20 Spider entries directly from the wheel without repository movement assets.
- Current README/core README/plan/validation-report local links passed the repository's link checker function.
- `verify_core.py` flags only six intended protected changes: core pyproject.toml, config.py, movement_cli.py, movement_controller.py, ninja_agent.py and web_server.py. Baseline hashes remain unchanged. Unrelated tracked bytecode produced by early tests was restored.
- Two earlier pytest processes remained heavily paging during teardown after reporting completed tests; only those identified test subprocesses were terminated (exit 143) to release memory. Their captured test results are retained; the full suite is not described as a clean process pass. The final feature suite exited normally. The robot's existing processes and daemon were untouched.

## Wiki evidence and discrepancies

Wiki search/source-status CLI was unavailable because the independent wiki environment is missing. No setup/dependency installation was attempted. Tracked pages were read directly: Motion System and Easing, Spider OTTO Waypoint Library, ninja_core, pi0servo, and Installation and Wiring. They are draft/unverified, with recorded passing AI semantic reviews; those reviews do not imply human/physical acceptance. Version-current complete manuals were resolved through project-knowledge.json. Baseline project-knowledge check passed before implementation.

Sources used include `src-20261009-2026-10-09-spider-otto`, `src-20261009-developmentguide`, `src-20261008-installationguide-3`, and historical core/servo README sources. Original relevant hashes are preserved:

| Registered original | SHA256 |
| --- | --- |
| Compatibility InstallationGuide | 734051f87ce7f447ae50bee7863118612f55b5747cd42e3cb047662a5408081f |
| Spider DevelopmentGuide | b8d75dba21189f9521728ca3726b00660c19cb77fb58bc6c619c7bb54a2c2708 |
| Spider DevelopmentLog | 26c761085d9ad415c759477dc2e33f92bb3feab89dabf58c917bbae373fb8dcc |
| Earlier Spider evidence note | 1c35301cb86c71126d626d841c5f648680fb82c8fe857526e22b983e970939cd |

Code supersedes historical manual claims about fixed movement durations and `/api/movements` routes. Those affected descriptions were corrected in the new candidate DevelopmentGuide. Earlier opt-in/unchanged-controller claims are explicitly historical. The new implementation now rejects unknown GPIOs and checks callbacks at waypoint boundaries, but still does not implement source periods/dwells or an oscillator controller. Physical calibration remains separate from config-key presence.

## Candidate sources for owner manual ingestion/review

- `raw/articles/ninjarobotpi0/2026-10-09-builtins/InstallationGuide.md`
- `raw/articles/ninjarobotpi0/2026-10-09-builtins/DevelopmentGuide.md`
- `raw/notes/ninjarobotpi0/2026-10-09-builtins/DevelopmentLog.md`
- `raw/articles/ninjarobotpi0/2026-10-09-builtins/README.md`
- `raw/articles/ninja_core/2026-10-09-builtins/README.md`
- `raw/notes/ninjarobotpi0/2026-10-09-builtins/BuiltinMovementsImplementationPlan.md`
- This evidence note and the final validation-report snapshot.

Affected page candidates: `wiki/concepts/spider-otto-waypoint-library.md`, `wiki/concepts/motion-system-and-easing.md`, `wiki/entities/ninja-core.md`, `wiki/references/api-and-cli-reference.md`, current installation/development reference pages, configuration/profile descriptions and `wiki/analyses/development-history-and-evolution.md`. Review code/source drift and new-file classification before updating implementation mappings. The owner will register/normalize evidence, prepare/review/apply the exact semantic diff, update current pointers/maps and run wiki quality gates after physical/manual validation. No current wiki completion gate is claimed here.

## Remaining limits and rollback

Spider's sampled trajectories are not qualified floor locomotion. Poweroff/hello/jump/scared include extreme poses or lost source waits. Wheel/Humanoid have only home. Arbitrary unscoped custom mechanics cannot be inferred from JSON. Callbacks do not interrupt inside a blocking driver step, and the controller lock is not a universal independent-writer lock. Existing CLI/agent post-task centering is separate from driver-abort handling.

Back up private config/calibration and support/disconnect actuator power before stopping an active runtime; shutdown can run Poweroff. Restore the reviewed previous runtime/config together if rolling back. Removing a built-in entry alone is temporary because import seeds it again. Registered old raw sources remain intact. No physical rollout was performed.

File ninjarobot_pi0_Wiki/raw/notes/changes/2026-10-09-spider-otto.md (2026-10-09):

# Spider OTTO implementation and movement contract evidence

Date: 2026-10-09. Actor: agent:codex. Owner-approved Pi0-only additive implementation.

## 2026-10-09: opt-in Spider OTTO waypoint library

The repository now contains `ninja_core/movements/spider_otto.json`, generated offline by `scripts/build_spider_movements.py`. Nineteen named entries cover sixteen OTTO movement functions plus selected directional variants; 565 steps use only the existing `moves` and `speed` fields. Existing `per_servo_speeds` remains supported by the unchanged controller and is tested separately. Source-ID-to-BCM mapping is S0→25, S1→24, S2→27, S3→26, S4→21, S5→20, S6→23, S7→22. The owner-supplied nominal conversion is q−90; Pi0 mounting direction remains unverified. No source S2 reversal or EEPROM trim is inferred for Pi0.

See `DevelopmentPlanDoc/SpiderBuildinMovements.md` for current schema examples, all movements, import-preview instructions and fidelity limits. The pack is a repository asset, not automatically loaded or installed as package data. It does not replace the live config or supply calibration. Existing movement functions, driver code, APIs, calibration and OTTO reference sources are unchanged.

Current movement steps use velocity-derived independent durations, wait for the slowest servo and choose easing by step position. They do not implement explicit pauses, exact periods or shared-time oscillator phases. Source jump/scared waits are omitted; hello is a documented partial adaptation of buggy state-dependent helpers. Unknown GPIO targets are silently omitted by the existing controller, and abort_check is not polled/forwarded; the pack does not improve cancellation guarantees.

`DevelopmentPlanDoc/Pi0BuildinMovementsRefinement.md` is a future-design reference only. It proposes a separate versioned registry/controller with timed poses, cancellable dwells, analytic oscillators, strict limits, shared monotonic time and exclusive output ownership. It does not add current fields or endpoints.

Host validation: 71 targeted pytest cases passed (Spider pack, config and API wrappers); Ruff checks/formatting passed for the two new Python files; generator --check and protected-core verification passed. No installation, physical robot execution or dynamics simulation occurred. Measured mapping/orientation, clearance, power, timing, balance and stop behavior remain pending owner-controlled Pi validation.

日本語: 19 個の動作定義を任意で読み込む JSON として追加しました。既存の動作制御関数は変更していません。元の周期・待機時間は再現しません。別の時間制御器は将来の提案のみで、実機検証は未実施です。

繁體中文：新增 19 個可選用的 JSON 動作定義，未修改既有動作控制函式。現有執行器不保留原始週期與停頓。獨立時間控制器僅為未來提案，尚未進行實機驗證。

简体中文：新增 19 个可选用的 JSON 动作定义，未修改现有动作控制函数。现有执行器不保留原始周期与停顿。独立时间控制器仅为未来提案，尚未进行实机验证。

The detailed two design documents are English; these summaries preserve the implementation boundary but are not full translations.

### Exact movement field and timing evidence

`ninja_core/src/ninja_core/movement_controller.py`: execute_movement converts JSON GPIO keys to integers, reads required moves/speed and optional per_servo_speeds. move_servos orders by driver pins; missing target is None; unknown pins never enter the list. Per-pin mode overrides the global mode. Calls move_all_sync(force=True) with easing single=in/out cubic, first=in cubic, middle=linear, last=out cubic. abort_check is not polled or passed to driver. A false completion with callback present automatically centers and raises EmergencyStop; without callback execution can advance.

`pi0servo/src/pi0servo/core/multi_servos.py`: shared elapsed monotonic loop with individual durations; waits for the longest. STEP_INTERVAL=.01s; timing is not a hard real-time guarantee. Starting a move clears driver abort events. Last angle/pulse estimate/center are command-state fallbacks, not encoder feedback. `motion/calculator.py` uses 600*(speed_percent/100)*{F:1,M:.75,S:.5}; duration=distance/velocity or zero for nonpositive velocity. The constant is an assumed motor spec. Cubic easing can peak at 3 times average velocity; these settings do not guarantee torque, protection, or velocity continuity.

`config.py`: movements is Dict[str,list], without deep step validation. `hal.py`: pins from core config but driver calibration read separately from servo.json. Driver absent calibration may use flat 1500/1500/1500; validated data bounds are not physical clearance. Servo.set_angle clamps pulse conversion but records requested angle. runtime_pipeline coordinates native/Blockly mode but is not universal servo ownership. Proposed scheduler must own cancellation and integrate exclusive writers.

### Source translation audit

Original OTTOKame.cpp uses signed sine amplitudes, offsets and phases. All 14 oscillator variants were compared to source arrays: run 0/1, turnL/R, dance, frontBack, upDown, pushUp, waveHAND, moonwalkL, omniWalk true/false factor2 and walk forward/backward. Walk feet have T/2; pause(1) refreshes every oscillator, so no opposite-diagonal hold. Source execute ignores steps and returns with oscillators active. The finite pack samples one cycle using 36 phase intervals (37 endpoint-inclusive poses), rounds to .001 degree, clips source angle to 0..180 then subtracts90 and permutes GPIO. Native M is an explicit target default, not inferred source speed.

Home/hide are single poses. Jump/scared use source three-pose order with unavailable pauses omitted. Hello uses actual zero-trim small helper writes (150ms divisor15, 500ms divisor50), then one 350ms-pattern wave; history, refresh interleaving and timestamp pause bug are not reproduced. Its S1 negative excursion is clipped. Source mounting S2 reversal and trim are not applied without target evidence. Mechanical fidelity is not claimed.

### Proposed design boundary

A separate future schema may support pose duration_ms, dwell duration_ms and analytic joints amplitude_deg/offset_deg/phase_deg/period_ms. These are proposals, not current config fields. Shared monotonic time, skip-stale deadline policy, command-owner cancellation and prevalidation are required. Repeated move_all_sync calls cannot preserve oscillator timing and reset abort flags. Peak oscillator velocity is 2*pi*abs(A)/Tseconds: walk A20,T275ms requires456.96deg/s, exceeding hypothetical M80 ceiling360. Reject or commonly stretch coupled periods; do not slow legs independently. No new controller is implemented.

### Host checks and provenance

71 tests passed on the existing temporary host environment. Tests use actual load_config and MovementController with a shuffled inert servo group; all565 steps, mapping, modes, easing, omissions and special source landmarks checked. Generator --check and Ruff passed. Protected-core check passed. No dependency installation, hardware command, runtime config edit or publication occurred.

- `scripts/build_spider_movements.py`: sha256:77491a278f891742924d7d4bfc247c6f9b1a18ab4e1effbf87c5f594c4be0d4a
- `ninja_core/movements/spider_otto.json`: sha256:6dee31d21fe57df2bf54deb568c10da000bc5e48b9c1f46a4921cf2ecf6bc547
- `tests/test_spider_movements.py`: sha256:80854b7bf60abe60e24ab39bdc625364bed2622754ec88a312e930322b6a1fb3
- `DevelopmentPlanDoc/SpiderBuildinMovements.md`: sha256:f63579266899081141bd3adb91ed74e15a52d78b8a0e1ad5c44bb81ffa46bda9
- `DevelopmentPlanDoc/Pi0BuildinMovementsRefinement.md`: sha256:d7c4dbd924d58e32bbc189b7e7a15ca1ae756cc63d2203d32bd068360e5a0fe8

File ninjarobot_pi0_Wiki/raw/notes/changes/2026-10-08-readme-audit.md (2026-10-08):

# Four-language README correctness audit — 2026-10-08

## Scope and owner direction
The owner supplied a four-language README and requested a correctness audit. The follow-up
explicitly retained intentional omissions and requested concise corrections, with necessary
recovery/check guidance only in Troubleshooting or appendices. The user-authored structure
is preserved. Only README and required knowledge provenance/navigation are edited.

## Verified corrections and code evidence
- scripts/install-rpi.sh exits on active pigpiod/ninjarobot before OS/Python installation.
  Its platform checker PASS is not installation success. README troubleshooting distinguishes
  Software installed from preflight, preserves calibration, stops robot service before daemon,
  disconnects actuator power before stopping hardware processes, and retries local checkout.
- scripts/install_check.py validates compatibility; pinned downloads are fallbacks. Bookworm/
  Trixie are reference OS releases, not a codename allowlist. README Appendix C preserves this.
- ninja_utils/src/ninja_utils/service_manager.py locates uv with shutil.which, checks config,
  pigpiod and ninja_core; install enables ninjarobot.service but does not start it. Unit ExecStart
  is uv run ninja_core server --autostart, so startup can sync Python dependencies. README uses
  the installer checker --find-tool uv and .venv/bin/ninja_utils commands, with PATH scoped to
  install-startup. It explains inactive-before-start and actual hostname/IP instead of a fixed
  ninjarobot.local URL or guaranteed one/two minute startup. Removal stops the service.
- ninja_core/src/ninja_core/web_server.py: run_server prompts for token; an existing token can
  be retained with Enter; normal input is not hidden. README directs token changes to onboarding.
  setup network code attempts ngrok even without configured token; skipping onboarding ngrok
  is not local-only mode. Autostart checks presence, not token validity. QR requires public URL
  and display. Power slider requests confirmation; shutdown attempts Poweroff movement and runs
  sudo shutdown. Animation success/idle LED do not guarantee OS shutdown.
- ninja_core/src/ninja_core/movement_cli.py parse_movement_command accepts numeric speed suffixes
  but rejects XF because a trailing speed after an alphabetic special target is not stripped.
  Replaced M_20:C/21:XF with M_20:C/21:45F. Positional servo guidance requires calibrated pins
  and mechanical limits; movement recording centers servos. Existing multi-step easing wording
  is retained: movement_controller selects ease-in, linear, ease-out by step position.
- English/Japanese/Traditional/Simplified Chinese corrections cover manual pigpiod activation,
  installation success, autostart, server behavior, credentials and recovery. Simplified Chinese
  autostart had copied Traditional Chinese prose; it is now Simplified Chinese.
- Clarified BCM versus physical pin numbers, 3.3 V GPIO logic versus module supply voltage,
  servo supply sizing, positional versus continuous-rotation servos, and UART/display pin conflicts.
- Google API usage is not guaranteed free. Quotas/model/region/billing and ngrok plan limits
  are account-dependent; source links remain in the manual. Credentials/config are private.

## External primary references inspected
https://www.raspberrypi.com/documentation/computers/configuration.html
https://ai.google.dev/gemini-api/docs/billing/
https://ai.google.dev/gemini-api/docs/pricing
https://github.com/ngrok/ngrok-docs/blob/main/pricing-limits/free-plan-limits.mdx
These support configuration/account caveats, not a claim of physical acceptance.

## Validation performed
- Read all four language sections and compared installer, checker, onboard launcher/wizard,
  service manager, server/ngrok/shutdown flow and both servo/core command parsers.
- bash -n parsed all 54 README shell blocks. No documented command was executed on hardware.
- Four corrected movement examples passed the isolated core parser using fixture definitions,
  without importing or initializing robot modules.
- Four-language command presence/parity, fenced-block balance and relative file links passed.
- Protected core source/metadata fingerprint check passed. No code, installer, lock or frontend edit.
- Required wiki plans/reviews/gates follow this evidence registration; no human verification claimed.

## Limits
No Pi, daemon, service, GPIO, calibration, server, account API or deployment was operated.
Documentation corrects existing behavior; it does not repair the legacy service implementation.
No new full runtime suite was needed for this documentation-only change. Old sources remain
immutable and retain historical wording.

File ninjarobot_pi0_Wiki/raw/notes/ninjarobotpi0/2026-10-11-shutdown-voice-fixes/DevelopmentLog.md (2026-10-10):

# NinjaRobotPi0 development log

## CLI launcher recovery — 2026-10-10

Current packaging delegates the five existing robot console commands exclusively to ninja_core/pi0servo/pi0disp/pi0buzzer/pi0vl53l0x. The root distribution remains ninjarobotpi0 but no longer duplicates those entry points. Installed root/provider RECORD files previously claimed the same launcher paths. Following the root rename, all five launchers were missing although their packages remained installed; normal sync did not repair them. The collision is confirmed. No prior transaction log establishes the exact deletion timing, so the rename-triggered removal is a grounded inference.

For an existing checkout containing this fix, use the normal user in a controlled maintenance session. Do not delete config/calibration or .venv. If another checkout is in use, publish the fix first, inspect git status and fast-forward its intended tracking branch; stop on errors and preserve local edits. Actual Python repair requires owner authorization and is distinct from diagnosis:

```bash
env -u UV_PROJECT_ENVIRONMENT -u UV_PROJECT uv sync --locked --inexact --no-dev \
  --reinstall-package ninja-core --reinstall-package pi0servo \
  --reinstall-package pi0disp --reinstall-package pi0buzzer \
  --reinstall-package pi0vl53l0x
uv run --no-sync ninja_core --help
./install.sh --check
```

This rebuilds changed root metadata plus the five local providers, preserving locked dependency versions and extra/development packages via --inexact. It does not start hardware or change system packages/services. Missing interpreter/dependencies instead require completing the full installer after its dry-run. The full installer now forces locked provider reinstallation and checks all five executable paths; uv must support --reinstall-package. Normal uv run may sync packages, while --no-sync uses an already repaired environment without synchronization.

Only after CLI help and software checks succeed AND physical readiness is confirmed may the owner start uv run --no-sync ninja_core server or .venv/bin/ninja_core server. This can initialize/center hardware and open ngrok; shutdown may execute Poweroff. No server/device tool was started for this repair. Direct module help passed without the launcher. 105 focused tests passed; full root regression passed 331 tests (exit 0)/1 intentionally excluded protected-baseline test with 31 existing dbus_next deprecation warnings. Ruff, shell syntax, offline lock check and installer/repair dry-runs passed. Real environment repair/repaired-launcher help remain pending owner approval; no package installation in the actual environment is claimed.

This is a complete English-only candidate derived from the preceding full 2026-10-10 lifecycle manual. Prior translated sections are not copied into this new version, and all original versions remain untouched. Historical sections below retain their dated status; this recovery section governs the current CLI behavior. Wiki registration/ingestion/review and current-pointer updates remain owner-deferred.

See [repair plan](../../../../../docs/CLIEntryPointRepairPlan.md) and [validation](../../../../../docs/validation/CLIEntryPoints-2026-10-10.md).

## Lifecycle refinements — 2026-10-10

This complete new version is raw evidence for owner manual validation and later ingestion/review. The owner reports the preceding built-in feature was ingested and semantically reviewed. This version does not change registered sources, curated pages, current pointers or review records. Earlier dated sections retain their historical validation status; the current lifecycle behavior below supersedes their exit/reconnect/prompt descriptions.

Movement-tool option 6 deliberately executes configured Poweroff before HAL shutdown and configuration save, without subsequent centering. If Poweroff is absent, configured home is attempted (the Wheel/Humanoid default). Invalid/incompatible/missing poses are logged and refused; cleanup/save still run. Keyboard interrupts and initialization failures do not request extra recovery motion. Startup still centers servos. Poweroff can command extreme Spider targets; physical clearance and power readiness are required. HAL shutdown releases PWM rather than electrically holding the final pose.

The shared Home/Agent/Help layout maintains /ws/session with a server-issued HttpOnly ninja_web_session cookie. One browser identity owns web controls; same-cookie tabs share ownership. A second browser gets busy/4409 and cannot access APIs or auxiliary sockets. Existing API paths/payloads and distance/events messages remain, but every /api/ request and /ws/distance or /ws/events socket now requires the live primary session. Inactive API requests return 423; requests during shutdown return 503. Scripted REST clients must get the cookie from HTML and keep /ws/session open. This is ownership, not login authentication; BLE is unchanged and remains a separate protocol.

Clients ping every 10 seconds, server timeout is 35 seconds without input, and browser retry is every 3 seconds. Final disconnect cancels pending browser requests/greetings, aborts ongoing native/Blockly work, stops output and restores the saved ngrok URL QR, falling back to reachable LAN URL if tunneling failed. No reachable URL means no QR. RuntimePipeline suppresses automatic idle painting while waiting. Startup QR and session cleanup/handoff are serialized; blocking ngrok/QR/display work runs off the asyncio thread. The QR remains square on rectangular displays. Missing/failing displays cannot retain ownership. Shutdown skips QR cleanup to preserve Poweroff. Cookie plus connection-generation context prevents old threads from regaining access after the same browser reconnects; centering receives an optional lifecycle abort callback checked inside the controller motion lock. Abort is cooperative, not an instantaneous hardware safety guarantee.

Root distribution/lock identity and the default virtual environment prompt are ninjarobotpi0. The directory remains .venv. Installer runs uv venv --allow-existing --prompt ninjarobotpi0 --python /usr/bin/python3 .venv before locked production sync, without --clear. uv compatibility now includes venv --allow-existing/--prompt/--python. Dependency versions are unchanged. Existing local activation scripts/pyvenv.cfg were mechanically updated without installation; re-activate an existing shell to see the new prompt.

Executed software checks: 72 inert movement/session/runtime tests and 93 installer/upgrade tests passed. Full root regression passed 319 tests, with one intentionally changed protected-baseline test excluded and 31 existing dbus_next deprecation warnings (exit 0). Focused Ruff, frontend lint/production build, shell syntax, offline lock check, install dry-run, prompt activation, Node hook harness and documentation links passed. Initial installer fixture failures were corrected by preventing host Node selection from bypassing mocked systemctl; no running service was stopped. Generated frontend assets were rebuilt. Protected-core and wiki-mapping gates intentionally remain drifted; no hashes are refreshed. No actual servo/display/network service acceptance or new semantic review is claimed.

See [implementation plan](../../../../../docs/LifecycleRefinementsImplementationPlan.md) and [validation report](../../../../../docs/validation/LifecycleRefinements-2026-10-10.md).

## 2026-10-09 — Automatic native built-in movements

Owner requested automatic robot-type movement import, CLI/web/Ninja agent integration, wrong-type execution prevention, a phased docs plan and robust local validation. Owner confirmed Wheel/Humanoid receive only an all-configured-servo center movement named home; future default gaits will be implemented later.

Added a package-resource catalog for Spider's 19 renamed trajectories and exact proposal Poweroff, scoped metadata and fingerprint-based idempotent import/type reconciliation preserving edits/custom collisions. Added shared discovery/preflight and controller execution guards, serialized native controller motion, boundary callback checks and stopping on driver abort. Agent text/audio output rejects entire invalid native chains; web validates before runtime reclamation and its dropdown logs rejected requests. Existing GPIO ordering/easing and legacy pack remain covered by inert regressions. Added explicit core wheel packaging for the JSON resource.

Documentation: docs/BuiltinMovementsImplementationPlan.md, docs/validation/BuiltinMovements-2026-10-09.md, README/core README and complete new dated raw manuals. Query evidence was read from tracked pages/current manuals because the wiki search environment is missing. Sources/pages are draft/unverified with recorded AI semantic review; no human/device verification is inferred.

Initial validation: 39 new feature checks and 60 existing targeted tests passed; generator --check and focused Ruff passed. Final host/frontend/package results are recorded in raw/notes/changes/2026-10-09-builtin-movements.md after validation completes. Six intended protected core/package changes are detected by verify_core.py; hashes remain unchanged for owner review. No dependencies were installed, no live model calls occurred, and no hardware was initialized or operated.

Final validation: 42 feature tests passed with normal exit; an earlier combined run reported 101 passed. Frontend lint/build, standalone wheel resource inclusion/loading, focused Ruff, generator reproducibility and documentation link checks passed. The local machine is Raspberry Pi Zero 2 W Rev 1.0 (aarch64), Python 3.13.5; automated tests used inert/mocked hardware. The earlier full suite reached 100% with three active-pigpiod installer environment failures and one intentional protected-core failure. That full-suite process and the earlier combined process were terminated only during prolonged paging teardown after test reporting; final feature validation exited normally. Physical device acceptance remains pending.

Owner explicitly deferred ingestion/review until manual validation. Registered originals, project-knowledge.json, curated pages, current pointers and semantic review records remain unchanged. New complete raw sources/evidence are candidates only; source/code drift is expected and wiki completion gates are not claimed. All Raspberry Pi mapping, direction, clearance, balance, timing, power and stop acceptance remain pending. In-step callback interruption, arbitrary custom movement mechanics and independent driver writer concurrency remain limitations.

## 2026-10-08 — compatibility rather than exact tool versions

## Software compatibility policy

The installer checks capabilities, not exact OS/Node/uv release equality:

- Raspberry Pi Zero 2 W, Linux `aarch64`, Debian-based Raspberry Pi OS (`ID=debian`
  or `raspbian`), and a normal user are required. No release-codename allowlist remains.
  Bookworm and Trixie are the reference targets; other releases are not automatically
  hardware-qualified merely because they pass preflight.
- Python 3.10+ is needed by existing runtime annotations (for example `ninja_core/config.py`
  and `pi0servo/core/servo.py`). Optional wiki development requires Python 3.11+.
  Existing metadata still says >=3.9; this installer check reflects the stricter runtime
  requirement without changing the robot packages. Locked dependencies remain authoritative.
- Node 20.19+ within 20.x, or Node >=22.12.0, matches the committed Vite 7/plugin engines.
  Node 24.21.0 qualifies. npm must be executable; `npm ci` and the build still have to succeed.
- uv has no exact-version gate. Its `sync --help` must expose `--locked`, `--no-dev`,
  `--python`, `--directory`, and `--all-extras`. uv 0.9.26 satisfies this and passed an
  offline host `sync --locked --no-dev --dry-run` against the existing lockfile.
  The capability probe alone does not certify every future uv version; real locked sync
  must succeed, with its original error preserved if it fails.
- Compatible tools on PATH are reused before compatible private tools. Missing/incompatible
  tools use checksum-verified fallback downloads. Download pins are not installed-version
  requirements. System tools and calibration files are retained. The existing pigpio daemon
  qualification remains separate and unchanged.

`./install.sh --check` stays read-only. Missing `.venv/bin/python` or `.venv/bin/ninja_core`
still means installation is incomplete: run `./install.sh`, wait for **Software installed**,
then run `./install.sh --check`. Publish/fetch this change before retrying on the Pi.
No physical Pi, hardware, account, or network-service acceptance is implied by host checks.

## 2026-10-08 — actionable installation recovery

Clarified the difference between inspection, Git update and actual installation. Added exact
version/path diagnostics and retry commands, robust timeout/exec handling, and installer failure
stage reporting with original exit status and temporary-lock cleanup. Tests preserve calibration
and prove check is read-only. README provides fast-forward default-HEAD steps for detached clones.
No robot core change, hardware activation or publication; real Pi follow-up remains pending.

## 2026-10-08 — Trixie installer rejection

The owner reported Debian 13/trixie on Zero 2 W. Both bootstrap and shared Python preflight
still enforced the earlier Bookworm-only requirement. Extended the allowlist to Bookworm/Trixie,
retained hardware/architecture/user/distribution guards, added release regression cases and
Python 3.11/3.13 CI. Updated current README/manuals/wiki without changing robot core or locks.
Host validation is recorded in `docs/validation/TrixieSupport-2026-10-08.md`; real Pi validation
and publication of this correction remain pending.

## 2026-10-08 — implementation audit and public README

Reviewed the approved upgrade against Pi5 terminal onboarding and README. Fixed pulse-alias
validation, credential first-write privacy, malformed/stale progress, real resume, retry/reuse flow,
worker platform enforcement, installer path/version/record handling, and wiki setup isolation.
Rewrote README with step-by-step curl/onboarding/testing, explicit runtime ngrok/servo boundaries,
and labelled multilingual summaries. Protected runtime/driver files remain unchanged.
New complete manual versions and source-grounded page reviews retain historical evidence.
Actual checks: see `docs/validation/UpgradeAudit-2026-10-08.md`; no physical Pi/account test or push.

## 2026-10-07 — approved installation, onboarding, wiki, and visual upgrade

Added a default-branch curl bootstrap, pinned/hash-checked software installer, and guided
Pi0 onboarding around existing interactive hardware tools and existing Gemini/ngrok helpers.
Moved the populated wiki to `ninjarobot_pi0_Wiki`; retained old raw originals and unmodified
page reviews. Added explicit wiki setup/prepare, read-only query/check, immutable manual versions,
current source/implementation mapping, policy/skill adapters, and regression checks.
Applied Pi5's navy/cyan design to Pi0's existing routes and controls, retaining their contracts.

Host validation and exact counts are recorded in `docs/validation/UpgradeValidation-2026-10-07.md`.
Core/driver source hashes and existing metadata/lockfiles are checked against the captured baseline.
No Raspberry Pi or live account test was run; owner final manual acceptance remains pending.
No commit/push/deployment was performed for this upgrade. Published curl endpoint acceptance remains
pending publication. Existing 2026-10-07 semantic reviews were preserved unless page content changed.

# Development Log

## 2026-09-01: Gemini 3.7 Flash No-Response Diagnosis And Runtime Fix ✓
- **Action**: Diagnosed and fixed the apparent no-response behavior after selecting `gemini-3.7-flash`.
- **Root Cause**:
  - `config.json` correctly contained `gemini-3.7-flash`, and the API key was present.
  - Google listed version `3.7-flash-08-2026` with `generateContent`, but a minimal request through the installed deprecated `google-generativeai 0.8.5` SDK timed out. The same key and network returned `200 OK` from `gemini-3-flash-preview`.
  - A direct REST request to Gemini 3.7 Flash succeeded with `thinkingLevel=low`. The installed legacy SDK has no thinking-configuration type, so its default Gemini 3 request could remain pending long enough to appear silent.
  - The project had no durable application log file. Direct chat errors were printed only to its console, and no `ninjarobot` systemd journal entries were available in the inspected environment.
- **Fix**:
  - Added `gemini_runtime.py`, which provides bounded, key-redacted REST generation for Gemini 3 models, applies the supported low thinking level, caps output, and moves blocking URL work to `asyncio.to_thread`.
  - Preserved the legacy SDK path for older Gemini models while adding an explicit request timeout.
  - Routed text chat, audio, code generation, explanation, and analysis through the appropriate bounded path without changing action-plan parsing or hardware execution.
  - Added a minimal generation probe before a selected model is persisted. Discovery, validation, timeout, or cancellation failures leave the previous key/model bytes unchanged.
  - Added model-specific startup and error diagnostics without logging API-key values.
- **Validation**:
  - Focused Gemini/config/init/agent tests passed (`39 passed`), Ruff passed, and all affected Python modules compiled.
  - The full root test suite passed (`104 passed`; 31 existing third-party DBus deprecation warnings), `git diff --check` passed, and the `ninja_core` source/wheel build included both Gemini modules. The build reported only the existing setuptools license-table deprecation warning.
  - A hardware-free live `NinjaAgent.process_command()` request using the saved `gemini-3.7-flash` model returned `READY` with a valid action plan. The full project prompt took approximately 35 seconds, confirming the model works but remains slower than the legacy default.
  - A subsequent 30-second validation probe timed out because Gemini 3.7 latency varied between calls, so the selection probe was aligned with the bounded 60-second runtime limit to avoid rejecting a working but slow model.
  - Earlier isolation checks showed Gemini 3.7 Flash timing out without thinking controls, succeeding with low thinking, and the legacy default returning `200 OK` using the same key/network.
  - No Raspberry Pi hardware, GPIO, servo, display, buzzer, or sensor validation was performed.
- **Files Modified**: `ninja_core/src/ninja_core/gemini_runtime.py`, `ninja_core/src/ninja_core/init_tool.py`, `ninja_core/src/ninja_core/__main__.py`, `ninja_core/src/ninja_core/ninja_agent.py`, `ninja_core/src/ninja_core/web_server.py`, `tests/test_gemini_runtime.py`, `tests/test_init_tool.py`, `tests/test_ninja_agent_model.py`, `DevelopmentGuide.md`, `InstallationGuide.md`, `ninja_core/README.md`, and `DevelopmentLog.md`.

## 2026-09-01: Gemini API Key Validation And Model Selection ✓
- **Action**: Replaced the fixed Gemini model setup path with API-key-specific model discovery and interactive selection for `uv run ninja_core config set-key gemini ...` and the guided `init-tool`.
- **Details**:
  - Added paginated Google Gemini model discovery over the official models REST endpoint, with `generateContent` filtering, deterministic ordering, finite timeouts, safe error messages, and no API key in request URLs or displayed errors.
  - Added backward-compatible `gemini.model` configuration. Existing files without this section retain the previous `gemini-3-flash-preview` behavior until setup is rerun.
  - Saved the Gemini key and selected model together only after successful discovery and selection; invalid keys, network failures, empty results, and cancellation leave the previous configuration unchanged.
  - Updated `NinjaAgent` initial creation and capability refresh to use the configured model while leaving prompts, chat/audio/code processing, action plans, BLE, web, and hardware behavior unchanged.
  - Preserved generic immediate-save behavior for non-Gemini `config set-key` services and preserved the existing web API key endpoint contract.
- **Validation**:
  - `PYTHONDONTWRITEBYTECODE=1 .venv/bin/python -m pytest tests -q` passed (`96 passed`; third-party `dbus_next` deprecation warnings only).
  - Standalone regression suites passed for `pi0buzzer` (`65 passed`), `pi0disp` (`57 passed`), and `pi0servo` (`82 passed`). The unrelated `pi0vl53l0x` suite produced 53 passing test progress markers but did not exit during teardown and was interrupted; no VL53L0X code changed.
  - `.venv/bin/ruff check ninja_core/src tests`, focused Ruff format checks for the new module/tests, and `git diff --check` passed.
  - A network smoke check using an intentionally invalid placeholder key reached Google's models endpoint and returned the expected redacted invalid-key error. No configured/local API key was used.
  - A single repository-wide pytest collection remains unsupported because package-local `tests` modules collide and the wiki package is not installed in the root environment; suites were therefore run from their owning package contexts.
  - No Raspberry Pi Zero 2W or robot hardware validation was performed. The configuration-only Pi smoke test remains pending and must not start the server or energize hardware.
  - Wiki source mirrors were synchronized for `src-20260822-developmentguide`, `src-20260822-developmentlog`, and `src-20260822-readme-3`. Source normalization, semantic plan generation, and wiki lint remain pending because the installed `uv` is older than the wiki's required version and the root environment lacks the wiki's `rich` dependency. Pre-existing README and Installation Guide mirror drift remains deliberately unsynchronized.
- **Files Modified**: `ninja_core/src/ninja_core/gemini_models.py`, `ninja_core/src/ninja_core/config.py`, `ninja_core/src/ninja_core/init_tool.py`, `ninja_core/src/ninja_core/__main__.py`, `ninja_core/src/ninja_core/ninja_agent.py`, `tests/test_gemini_models.py`, `tests/test_ninja_agent_model.py`, `tests/test_config.py`, `tests/test_init_tool.py`, `README.md`, `ninja_core/README.md`, `DevelopmentGuide.md`, `InstallationGuide.md`, `DevelopmentLog.md`, and the deterministically synchronized wiki source snapshots/catalog records for the three source IDs above.

## 2026-09-01: Developer Quality Tooling And Codex MCP Setup ✓
- **Action**: Added reproducible Python quality tools and prepared the local Codex CLI with semantic code-navigation and current-library documentation MCP servers without changing robot runtime behavior.
- **Details**:
  - Added `pytest` and `ruff` to the root `dependency-groups.dev` lock-backed development environment.
  - Installed and initialized Serena 1.7.0 with its LSP backend; Serena migrated `.serena/project.yml` to its current schema while retaining Python analysis and project-root indexing.
  - Registered Serena with Codex's `codex` context and current-directory project activation, and registered Context7 through its maintained npm MCP package.
  - Added explicit MCP startup timeouts in the user-level Codex configuration because Serena's cold startup exceeds Codex's default ten-second window on this machine.
- **Why**: Make the upcoming Gemini configuration work testable and lintable from the repository environment, while giving Codex symbol-aware repository navigation and current third-party library documentation.
- **Validation**: `uv run pytest tests/test_config.py tests/test_init_tool.py -q` passed (`11 passed`); focused `uv run ruff check` passed. Direct MCP JSON-RPC initialization and `tools/list` probes passed for Serena (`23` tools) and Context7 (`resolve-library-id`, `query-docs`). No Raspberry Pi or robot hardware validation was required or performed because this change only affects developer tooling.
- **Files Modified**: `pyproject.toml`, `uv.lock`, `.serena/project.yml`, `DevelopmentGuide.md`, and `DevelopmentLog.md`. User-level installations/configuration were also updated under the uv tool directory, `~/.serena/`, and `~/.codex/config.toml`.

## 2026-09-01: Cross-Tool Local Wiki Development Workflow ✓
- **Action**: Integrated `Wiki/NinjaRobotPi0_Wiki` into the NinjaRobotV5 AI-assisted development workflow without changing robot runtime behavior.
- **Details**:
  - Added canonical `AGENTS.md` instructions with evidence retrieval, conflict handling, physical safety, documentation, validation, and wiki-maintenance gates; retained `AGENT.md` as a legacy pointer.
  - Added Claude Code, Google Antigravity, and Cursor adapters that route to the same canonical policy.
  - Added portable `robot-wiki-query` and `robot-wiki-maintain` skills, Claude wrappers, and Antigravity workflows.
  - Added `project-sources.toml` and a deterministic source-mirror checker so project document drift is visible before wiki knowledge is updated.
  - Refined the driver, documentation, and Raspberry Pi validation skills to use wiki evidence and report maintenance state.
  - Added `WikiIntegrationWorkflowPlan.md` and documented the workflow in `README.md`, `DevelopmentGuide.md`, and the embedded wiki README/AGENTS files.
- **Why**: Give Codex, Claude Code, Google Antigravity, and Cursor the same local source of truth and prevent stale or conflicting documents from being silently copied into future robot work.
- **Validation**: Documentation/skill validation, source-mirror checks, wiki lint/tests, and parent Git inclusion checks are recorded in the task handoff. No Raspberry Pi validation was required because no robot code, configuration, deployment, or hardware behavior changed.
- **Files Modified**: `AGENTS.md`, `AGENT.md`, `CLAUDE.md`, `GEMINI.md`, `.agents/`, `.claude/`, `.cursor/`, `README.md`, `DevelopmentGuide.md`, `DevelopmentLog.md`, `WikiIntegrationWorkflowPlan.md`, and workflow files under `Wiki/NinjaRobotPi0_Wiki/`.

## 2026-05-17: Code IDE Assistant Compatibility Note ✓
- **Action**: Synchronized NinjaRobotV5 documentation with the browser-side Ninja Code Assistant enhancement.
- **Details**:
  - Confirmed no NinjaRobotV5 runtime code change was required for the first assistant enhancement phase.
  - Documented that browser-side assistant comments/explanations must not alter `execute`, `save_action`, `stop`, or runtime pipeline behavior.
  - Reaffirmed that BYO AI provider API keys are not robot configuration and must not be stored in `config.json`, saved action records, or BLE payloads.
  - Reaffirmed that future Tire/Humanoid/Spider-specific assistant generation should use `robot_info` only as read-only profile context unless a later robot-side contract explicitly changes this.
- **Validation**: Paired platform validation passed in `NinjaRoboticPlatform` with `npm run lint`, `npm run test` (`92 passed`), `npm run build`, and browser smoke checks. RobotV5 code was not modified in this phase.
- **Files Modified**: `DevelopmentGuide.md`, `DevelopmentLog.md`, `InstallationGuide.md`.

## 2026-05-16: Guided Initialization And Robot Profile Sync ✓
- **Action**: Added the NinjaRobotV5 guided initialization flow and BLE robot profile synchronization for the NinjaRoboticPlatform Code IDE.
- **Details**:
  - **Config model**: Added `robot_type` (`tire`, `humanoid`, `spider`), validation helpers, sanitized hardware profile serialization, and explicit `hardware_configuration.servos.gpio_pins`.
  - **Interactive setup**: Added `uv run ninja_core init-tool` with menu actions for Gemini API key, ngrok token, robot rename, robot type, hardware import, sanitized config display, server start, and exit.
  - **BLE profile**: Extended `NinjaBLEService` `robot_info` responses with robot type and sanitized hardware configuration while preserving name-only fallback behavior for older IDEs and profile serialization failures.
  - **ngrok setup**: Extracted lightweight ngrok token helpers so token setup can run without initializing the web server or robot hardware.
- **Validation**: `PYTHONDONTWRITEBYTECODE=1 uv run --with ruff ruff check ninja_core/src ninja_ble/src tests` passed. `PYTHONDONTWRITEBYTECODE=1 PYTHONPATH=ninja_ble/src:ninja_core/src:ninja_utils/src:pi0buzzer/src:pi0disp/src:pi0servo/src uv run --with pytest --with pillow python -m pytest tests` passed (`76 passed`).
- **Files Modified**: `ninja_core/src/ninja_core/config.py`, `ninja_core/src/ninja_core/init_tool.py`, `ninja_core/src/ninja_core/ngrok_config.py`, `ninja_core/src/ninja_core/__main__.py`, `ninja_core/src/ninja_core/web_server.py`, `ninja_ble/src/ninja_ble/service.py`, `tests/test_config.py`, `tests/test_init_tool.py`, `tests/test_ble_service.py`, `DevelopmentGuide.md`, `InstallationGuide.md`, `DevelopmentLog.md`.

## 2026-05-06: BLE Save Status Readback Refinement ✓
- **Action**: Hardened BLE Save to Robot confirmations so a successful Blockly action save on the Pi no longer appears as `Response timeout for action_save_status` when Chrome misses the notification event.
- **Implementation**:
  - **Command response cache**: `NinjaBLEService` now caches final `action_save_status` events by `request_id` for deterministic readback.
  - **Status characteristic**: Added Command Status characteristic `00000004-710e-4a5b-8d75-3e5b444bc3cf` for browser polling via `get_command_response`.
  - **Notification sizing**: Outbound BLE notifications now chunk above a conservative 160-byte payload threshold instead of relying on the previous 500-byte single-notification limit.
  - **Compatibility**: The existing Response characteristic remains the live notification stream for older Code IDE clients.
- **Validation**: `uv run --with pytest pytest tests` passed (`67 passed`). `uv run --with ruff ruff check ninja_ble/src/ninja_ble/service.py tests/test_ble_service.py tests/test_chunking.py` passed. Repo-wide `uv run --with pytest pytest` and `uv run --with ruff ruff check .` still encounter unrelated pre-existing sibling-package collection/lint issues in `pi0*` test folders.
- **Files Modified**: `ninja_ble/src/ninja_ble/service.py`, `tests/test_ble_service.py`, `README.md`, `DevelopmentGuide.md`, `DevelopmentLog.md`.

## 2026-04-30: Saved Action Overwrite And Agent Interruption Refinement ✓
- **Action**: Refined saved Blockly action collision handling and web-agent interruption behavior for long-running saved actions.
- **Implementation**:
  - **Protected overwrite**: `ActionLibrary.save_action(..., overwrite=True)` can replace existing saved Blockly actions while preserving native `config.json` movements from overwrite.
  - **Collision metadata**: `action_save_status` now includes `can_overwrite` and `overwritten` so the Code IDE can distinguish saved-action conflicts from protected native movement conflicts.
  - **BLE response fallback**: `NinjaBLEService` now sends a save-action response fallback from the dispatcher result, preventing browser-side `action_save_status` timeouts during collision handling.
  - **Agent interruption**: New web-agent messages call a cooperative interruption path that stops active SafeExecutor code, aborts servos, stops face/sound output, and serializes action-plan execution with an async lock before running the new command.
  - **Safety limit**: Non-cooperative Python loops that never reach `check_stop()` are not force-killed in-thread; the server returns a safety warning instead of starting a second robot action on top of the first.
- **Validation**: `PYTHONDONTWRITEBYTECODE=1 uv run --with ruff ruff check ninja_core/src ninja_ble/src tests` passed. `PYTHONDONTWRITEBYTECODE=1 PYTHONPATH=ninja_ble/src:ninja_core/src:ninja_utils/src:pi0buzzer/src:pi0disp/src:pi0servo/src uv run --with pytest --with pillow python -m pytest tests` passed (`64 passed`).

## 2026-04-29: Saved Blockly Action Library Refinement ✓
- **Action**: Added a persistent saved-action pipeline so complete Blockly programs uploaded from the NinjaRoboticPlatform Code IDE can be named, stored on the robot, and replayed by the NinjaRobotV5 AI agent.
- **Implementation**:
  - **Action library**: Added `ninja_core.action_library.ActionLibrary`, storing validated `ninja-action-v1` records in `ninja_actions/*.json` with generated Python, Blockly workspace metadata, manifest, normalized name, slug, and timestamps.
  - **Robot-authoritative conflicts**: The Pi now rejects action names that conflict with native `config.json` movements or existing saved Blockly actions and returns `action_save_status` with `code: action_name_conflict`.
  - **BLE command contract**: `CommandDispatcher` now handles `save_action`, broadcasts saved/conflict/error status events, and refreshes agent capabilities after a successful save.
  - **AI replay path**: `NinjaAgent` now exposes saved Blockly action names in its prompt and may return `action_chain`; `web_server.execute_action_plan()` replays that chain through `CommandDispatcher.execute_action_chain()` and the SafeExecutor/runtime-pipeline path.
  - **Documentation**: Updated `README.md` and `DevelopmentGuide.md` with the saved action library, BLE command/event contract, replay behavior, and validation rules.
- **Validation**: `PYTHONDONTWRITEBYTECODE=1 uv run --with ruff ruff check ninja_core/src ninja_ble/src tests` passed. `PYTHONDONTWRITEBYTECODE=1 PYTHONPATH=ninja_ble/src:ninja_core/src:ninja_utils/src:pi0buzzer/src:pi0disp/src:pi0servo/src uv run --with pytest --with pillow python -m pytest tests` passed (`62 passed`).
- **Files Modified**: `ninja_core/src/ninja_core/action_library.py`, `ninja_core/src/ninja_core/contracts.py`, `ninja_core/src/ninja_core/dispatcher.py`, `ninja_core/src/ninja_core/ninja_agent.py`, `ninja_core/src/ninja_core/web_server.py`, `ninja_core/src/ninja_core/__main__.py`, `tests/test_action_library.py`, `tests/test_contracts.py`, `tests/test_dispatcher.py`, `README.md`, `DevelopmentGuide.md`, `DevelopmentLog.md`.

## 2026-04-23: BLE Robot Naming Refinement ✓
- **Action**: Added persistent Bluetooth naming support so each NinjaRobotV5 can advertise a user-defined discovery name instead of relying on the shared default.
- **Details**:
  - **Config model**: Added `bluetooth.name` to `config.json`, BLE-safe normalization, and `set_robot_name()` in `ninja_core.config`.
  - **CLI command**: Added `uv run ninja_core config set-name "<name>"` to save a custom robot name for future BLE sessions.
  - **BLE runtime**: Updated `NinjaBLEService` to advertise the configured name through both Bless server startup and the compact BlueZ advertisement fallback.
  - **Web status**: Updated `web_server.py` to start BLE with the saved name and report the configured name from `/ble/status`.
  - **Documentation**: Added Installation Guide section `7.7 Name your robot` and refreshed the Development Guide config, CLI, BLE, and config.json reference sections.
- **Validation**: `uv run --with ruff ruff check ninja_core/src ninja_ble/src tests` passed. `PYTHONDONTWRITEBYTECODE=1 PYTHONPATH=ninja_ble/src:ninja_core/src:ninja_utils/src:pi0buzzer/src:pi0disp/src:pi0servo/src uv run --with pytest --with pillow python -m pytest tests/test_ble_service.py tests/test_config.py` passed (`7 passed, 1 skipped`). `PYTHONDONTWRITEBYTECODE=1 PYTHONPATH=ninja_ble/src:ninja_core/src:ninja_utils/src:pi0buzzer/src:pi0disp/src:pi0servo/src uv run --with pytest --with pillow python -m pytest tests` passed (`49 passed, 1 skipped`).
- **Files Modified**: `ninja_core/src/ninja_core/config.py`, `ninja_core/src/ninja_core/__main__.py`, `ninja_core/src/ninja_core/web_server.py`, `ninja_ble/src/ninja_ble/service.py`, `tests/test_ble_service.py`, `tests/test_config.py`, `InstallationGuide.md`, `DevelopmentGuide.md`, `DevelopmentLog.md`.

## 2026-04-23: Blockly Text & Music Contract Refinement ✓
- **Action**: Added Pi-side text/music wrapper APIs for Blockly and synchronized the runtime documentation with the new Show Text and Play Music blocks.
- **Details**:
  - **Display text API**: Added shared centered-text rendering and `robot.display.text(...)` with static/scrolling modes, cooperative duration handling, and ticker cleanup on stop or disconnect.
  - **Built-in songs**: Added `happy_birthday`, `jingle_bells`, `twinkle_twinkle_little_star`, and `head_shoulders_knees_and_toes` to `pi0buzzer.notes`, plus `MusicBuzzer.play_named_song()` and `robot.buzzer.play_song()`.
  - **Stop cleanup**: `RobotWrapper.request_stop()` now stops active scrolling text before native idle is restored, matching the Code IDE Stop Robot and Disconnect contract.
  - **Documentation**: Updated `DevelopmentGuide.md` with V5.2.8 notes, the new buzzer/display APIs, and Blockly text/music examples.
- **Validation**: `uv run --with ruff ruff check ninja_core/src pi0disp/src pi0buzzer/src tests pi0disp/tests pi0buzzer/tests` passed. `PYTHONDONTWRITEBYTECODE=1 PYTHONPATH=ninja_ble/src:ninja_core/src:ninja_utils/src:pi0buzzer/src:pi0disp/src:pi0servo/src uv run --with pytest --with pillow python -m pytest tests` passed (`45 passed, 1 skipped`). `PYTHONDONTWRITEBYTECODE=1 PYTHONPATH=src uv run --with pytest --with pillow python -m pytest tests` passed in `pi0disp` (`57 passed`). `PYTHONDONTWRITEBYTECODE=1 PYTHONPATH=src uv run --with pytest python -m pytest tests` passed in `pi0buzzer` (`65 passed`). Paired Code IDE validation also passed with focused Blockly tests, full `npm test -- --run`, `npm run lint`, and `npm run build`.
- **Files Modified**: `pi0disp/src/pi0disp/effects/text_ticker.py`, `pi0disp/src/pi0disp/cli/text_cmd.py`, `pi0disp/tests/test_text_ticker.py`, `pi0buzzer/src/pi0buzzer/notes.py`, `pi0buzzer/src/pi0buzzer/core/music.py`, `pi0buzzer/tests/test_music.py`, `ninja_core/src/ninja_core/api_wrappers.py`, `tests/test_api_wrappers.py`, `DevelopmentGuide.md`, `DevelopmentLog.md`.

## 2026-04-23: Blockly GPIO Motion Contract Refinement ✓
- **Action**: Added GPIO-first servo wrapper APIs for Blockly-generated motion code and synchronized the Pi runtime docs with the Code IDE motion changes.
- **Details**:
  - **GPIO servo API**: `ServoArrayWrapper` now exposes `move_pin(pin, angle, speed_mode="M")` and `move_pins({pin: angle}, per_servo_speeds={...})` for GPIO-addressed motion.
  - **Speed-mode routing**: Wrapper calls normalize `F`/`M`/`S` speed modes, clamp Blockly angles to `-90..90`, reject unknown GPIO pins, and forward synchronized targets to pi0servo `move_all_sync()`.
  - **Compatibility**: Existing native/direct APIs such as `robot.servo[n]`, `robot.servos.move_all()`, and other `ninja_core` wrappers remain available for Raspberry Pi web-interface and legacy script use.
  - **Protocol default**: Updated the Pi-side default Blockly generator manifest to `web-blockly-v2`, while still accepting sender-provided manifest overrides.
  - **Documentation**: Updated `DevelopmentGuide.md` with V5.2.7 notes and the `web-blockly-v2` GPIO/speed/multi-servo examples.
- **Validation**: `PYTHONDONTWRITEBYTECODE=1 uv run --with ruff ruff check ninja_core/src tests` passed. `PYTHONDONTWRITEBYTECODE=1 PYTHONPATH=ninja_ble/src:ninja_core/src:ninja_utils/src:pi0buzzer/src:pi0servo/src uv run --with pytest --with pillow python -m pytest tests` passed (`41 passed, 1 skipped`). Paired Code IDE validation also passed with focused Blockly tests, full `npm test -- --run`, `npm run lint`, and `npm run build`.
- **Files Modified**: `ninja_core/src/ninja_core/api_wrappers.py`, `ninja_core/src/ninja_core/contracts.py`, `tests/test_api_wrappers.py`, `tests/test_contracts.py`, `DevelopmentGuide.md`, `DevelopmentLog.md`.

## 2026-04-23: Native/Blockly Dual Pipeline Refinement ✓
- **Action**: Fixed Blockly BLE expression/display ownership conflicts by separating native robot behavior from uploaded Blockly execution.
- **Root Cause**: Blockly execution could create or use display/sound actions independently from the native idle pipeline, allowing uploaded expressions or display clears to race with the web server's idle face animation.
- **Details**:
  - **RuntimePipeline**: Added a native/Blockly ownership coordinator that stops native face, sound, and servo output when valid Blockly code starts.
  - **Shared face engine**: `SafeExecutor` and `RobotWrapper` now reuse the native `AnimatedFaces` instance so `robot.expression("angry")` does not overlap with idle animation.
  - **Display clear hold**: `robot.display.clear()` now keeps the display blank after successful Blockly completion until native interaction, the next upload, Stop Robot, or Disconnect restores ownership.
  - **Stop/disconnect restore**: Dispatcher stop handling aborts Blockly ownership and resumes native idle; direct web actions reclaim native mode before running.
  - **Documentation**: Updated `DevelopmentGuide.md` with the dual-pipeline contract, affected APIs, and BLE stop/disconnect behavior.
- **Validation**: `PYTHONPATH=ninja_ble/src:ninja_core/src:ninja_utils/src:pi0buzzer/src:pi0servo/src uv run --with pytest --with pillow python -m pytest tests` passed (`37 passed, 1 skipped`). `uv run --with ruff ruff check ninja_core/src tests` passed. Paired IDE validation in `NinjaRoboticPlatform` also passed with `npm test -- --run` and `npm run lint`.
- **Files Modified**: `ninja_core/src/ninja_core/runtime_pipeline.py`, `ninja_core/src/ninja_core/api_wrappers.py`, `ninja_core/src/ninja_core/dispatcher.py`, `ninja_core/src/ninja_core/robot_sound.py`, `ninja_core/src/ninja_core/safe_executor.py`, `ninja_core/src/ninja_core/web_server.py`, `tests/test_api_wrappers.py`, `tests/test_dispatcher.py`, `tests/test_runtime_pipeline.py`, `DevelopmentGuide.md`, `DevelopmentLog.md`.

## 2026-04-22: Documentation Synchronization Audit ✓
- **Action**: Reviewed `DevelopmentGuide.md` and the affected `pi0vl53l0x/README.md` against the latest Blockly-driven distance-sensor concurrency and recovery changes.
- **Details**:
  - **VL53L0X docs**: Updated `pi0vl53l0x` feature and API documentation to describe transaction-level ranging locks, thread-safe `reinitialize()`, and shared use by the background monitor plus Blockly `robot.distance.read()`.
  - **Core docs**: Corrected `DistanceMonitor.get_continuous_distance()` unavailable-reading semantics from `0` to `-1`, matching the current runtime behavior before `DistanceWrapper` converts invalid Blockly reads to `9999`.
  - **Test inventory**: Updated `pi0vl53l0x` test counts from 60 to 61 and documented the new transaction-lock sensor test.
- **Validation**: Performed a line-by-line documentation audit with Serena symbol/pattern checks against `VL53L0X`, `DistanceMonitor`, and `DistanceWrapper`; followed with stale-text searches for outdated thread-safety and test-count claims. `uv run --with ruff ruff check ninja_core/src pi0vl53l0x/src tests pi0vl53l0x/tests` passed.
- **Files Modified**: `DevelopmentGuide.md`, `pi0vl53l0x/README.md`, `DevelopmentLog.md`.

## 2026-04-22: VL53L0X Blockly Concurrency & Recovery Fix ✓
- **Action**: Fixed VL53L0X failures observed when Blockly code repeatedly called `robot.distance.read()` while the server's background distance monitor was also active.
- **Root Cause**: `I2CBus` serialized individual byte operations, but `VL53L0X.get_range()` and `get_data()` perform multi-step single-shot ranging transactions. The background monitor and Blockly user code could interleave register writes, causing I2C retries, bus recovery, invalid `-1` readings, and a permanently stopped monitor thread.
- **Details**:
  - **Measurement lock**: Added a `threading.RLock` around whole VL53L0X ranging transactions and runtime reinitialization/close.
  - **Monitor recovery**: `DistanceMonitor` now keeps running after transient I2C failures, marks cached distance unavailable, and attempts `sensor.reinitialize()` after repeated failures.
  - **Blockly safety fallback**: `robot.distance.read()` now returns the documented `9999` fallback for invalid or unavailable sensor data instead of returning `-1`, preventing failed reads from triggering near-obstacle branches.
  - **CLI lint cleanup**: Fixed unused imports in the VL53L0X CLI entrypoint so the expanded package lint gate is clean.
- **Validation**: `uv run --with ruff ruff check ninja_core/src pi0vl53l0x/src tests pi0vl53l0x/tests`, `PYTHONPATH=ninja_ble/src:ninja_core/src:ninja_utils/src uv run --with pytest --with pillow python -m pytest tests`, and `PYTHONPATH=pi0vl53l0x/src uv run --with pytest python -m pytest pi0vl53l0x/tests` passed.
- **Files Modified**: `pi0vl53l0x/src/pi0vl53l0x/core/sensor.py`, `pi0vl53l0x/src/pi0vl53l0x/__main__.py`, `pi0vl53l0x/src/pi0vl53l0x/cli/sensor_tool.py`, `ninja_core/src/ninja_core/perception.py`, `ninja_core/src/ninja_core/api_wrappers.py`, `pi0vl53l0x/tests/test_sensor.py`, `tests/test_api_wrappers.py`, `tests/test_perception.py`, `DevelopmentGuide.md`.

## 2026-04-21: Blockly Syntax Error Runtime Refinement ✓
- **Action**: Hardened Pi-side Blockly execution handling after a generated indentation error caused hardware cleanup even though user code never started.
- **Details**:
  - **Syntax preflight**: `SafeExecutor.execute()` now compiles code before starting the execution thread.
  - **Hardware safety**: Syntax failures return immediately without calling `robot.request_stop()`, preventing unnecessary display, buzzer, or servo shutdown.
  - **Structured errors**: `contracts.build_error_event()` can include structured `details`; `CommandDispatcher` broadcasts syntax error line data through the normal BLE feedback contract.
  - **Executor recovery**: Added tests proving valid code can run immediately after a syntax failure.
- **Validation**: `uv run --with ruff ruff check ninja_core/src tests` and `PYTHONPATH=ninja_ble/src:ninja_core/src:ninja_utils/src uv run --with pytest --with pillow python -m pytest tests/test_safe_executor.py tests/test_dispatcher.py tests/test_contracts.py` passed.
- **Files Modified**: `ninja_core/src/ninja_core/safe_executor.py`, `ninja_core/src/ninja_core/dispatcher.py`, `ninja_core/src/ninja_core/contracts.py`, `tests/test_safe_executor.py`, `tests/test_dispatcher.py`, `tests/test_contracts.py`, `DevelopmentGuide.md`.

## 2026-04-21: Blockly Runtime Reliability Refinement ✓
- **Action**: Closed the remaining Phase 5 classroom-reliability gaps identified during the secondary Blockly/BLE audit.
- **Details**:
  - **Request lifecycle fix**: `dispatcher.py` now preserves the active execution `request_id` when a second `execute` request is rejected, so stop/log/status/error broadcasts remain correlated to the original run.
  - **Runtime feedback fidelity**: Removed the 120-character execution-log truncation now that outbound BLE chunking handles large runtime feedback safely.
  - **Tests**: Added dispatcher coverage for rejected duplicate runs and full-length execution-log broadcasts.
  - **Documentation**: Updated `DevelopmentGuide.md` to document the versioned Blockly `execute`/`stop` contract, BLE transport-v2 ACK envelopes, and the event stream consumed by the IDE.
- **Validation**: `uv run --with ruff ruff check NinjaRobotV5/ninja_core/src NinjaRobotV5/tests` and targeted `pytest NinjaRobotV5/tests/test_dispatcher.py` passed.
- **Files Modified**: `ninja_core/src/ninja_core/dispatcher.py`, `tests/test_dispatcher.py`, `DevelopmentGuide.md`.

## 2026-02-26: Cross-Documentation Content Audit & Corrections ✓
- **Action**: Performed a full, line-by-line audit of `README.md`, `DevelopmentGuide.md`, and `InstallationGuide.md` to ensure all information perfectly matches the newly rebuilt V5 hardware libraries (`pi0servo`, `pi0disp`, `pi0vl53l0x`, and `pi0buzzer`).
- **Issues Found & Fixed**:
  - **InstallationGuide.md**: Corrected the display hardware specification from "240x240 pixels" to the accurate "240x320 pixels" across all three languages (English, Japanese, Traditional Chinese). 
  - **DevelopmentGuide.md**: Fixed the architecture dependency graph, correcting the pi0disp linkage. Removed duplicate lines in the ninja_utils API section. Verified all library API sub-sections (including `ninja_core`) against the actual source code, confirming that previous log updates had successfully kept the API references accurate.
  - **README.md**: Updated the OS compatibility badge, bumped the copyright year to 2026 in the translation sections, and ensured library feature descriptions correctly highlight the non-blocking architectures of the rebuilt libraries. 
- **Validation**: Manual reading, file structure comparisons, and `grep` verifications. All documentation files are now fully synchronized with the 5.3.0 codebase.
- **Files Modified**: `README.md`, `DevelopmentGuide.md`, `InstallationGuide.md`.

## 2026-02-26: DevelopmentGuide.md & InstallationGuide.md — pi0buzzer Section Updates ✓
- **Action**: Reviewed and updated all pi0buzzer-related content in `DevelopmentGuide.md` and `InstallationGuide.md` to reflect the rebuilt V1.0.0 library.
- **DevelopmentGuide.md changes**:
  - Replaced 3-file file tree with full 16-file modular structure (core/, config/, cli/, tests/, notes.py).
  - Updated dependency graph: `ninja_utils` now marked optional.
  - Rewrote section 3.2 from 2 subsections to 5: notes.py, Buzzer class, MusicBuzzer class, BuzzerConfigManager, CLI commands.
  - Fixed constructor signature: old `(pi, pin)` → new `(pin, pi, volume)`.
  - Corrected behavior: old "Blocking: Yes" → new "Non-blocking" for all methods.
  - Added new CLI commands: `play`, `info`, `config show/export/import`, `buzzer-tool`.
  - Updated `buzzer.json` format to include `volume` field.
- **InstallationGuide.md changes**:
  - Replaced `uv run pi0buzzer playmusic` with `uv run pi0buzzer play happy` in all 3 language sections (EN, JP, ZH).
- **Files Modified**: `DevelopmentGuide.md`, `InstallationGuide.md`.

## 2026-02-26: pi0buzzer Standalone Mode Fix & Minor Audit Findings ✓
- **Action**: Fixed critical `ModuleNotFoundError: No module named 'ninja_utils'` when running pi0buzzer standalone (outside NinjaRobotV5 workspace). Applied conditional `try/except` imports to `core/driver.py`, `core/music.py`, and `config/config_manager.py` — matching the pattern established by `pi0disp` and `pi0servo`.
- **Details**:
  - **Actuator fallback**: When `ninja_utils` is absent, a minimal local `Actuator(ABC)` is defined inline.
  - **Logger fallback**: Falls back to standard `logging.getLogger(__name__)` when `ninja_utils.get_logger` is unavailable.
  - **pigpio fallback**: `pigpio = None` when not installed (for PC/Mac dev).
  - **`from __future__ import annotations`**: Added to `core/driver.py` and `core/music.py` so `pigpio.pi` type hints are lazily evaluated (prevents `AttributeError` when `pigpio = None`).
  - **F4**: `beep` CLI argument changed from `float` to `int` for frequency.
  - **F5**: `export_config()` now calls `save()` before `shutil.copy2()` to ensure in-memory changes are included.
- **Validation**: `ruff check` clean, 61/61 pytest tests pass.
- **Files Modified**: `core/driver.py`, `core/music.py`, `config/config_manager.py`, `__main__.py`, `RebuildPlan.md`.

## 2026-02-26: pi0buzzer Library Full Rewrite & ninja_core Integration ✓
- **Action**: Completely rebuilt the `pi0buzzer` library (Phase 8 of ProjectUpgradePlan). Replaced old blocking driver with a robust, architecture-aligned library featuring `Buzzer`, `MusicBuzzer`, `BuzzerConfigManager`, and an interactive TUI CLI (`buzzer-tool`).
- **Key Features**:
  - **Non-blocking Playback**: Background worker thread supports single tones, songs, and pauses safely alongside asyncio (`__pause__` support in queue).
  - **Shared Notes module**: `pi0buzzer.notes` unifies note frequencies, keyboard mappings, and `EMOTION_SOUNDS`.
  - **Config Management**: JSON configuration with validation, fallback defaults, and import/export capabilities.
  - **Interactive CLI**: Menu-driven `buzzer-tool` matching the `servo-tool` and `display-tool` paradigms, enabling hardware testing, config management, health-checks, and a live keyboard piano mode.
  - **100% Test Pass Rate**: 61/61 unit tests passing utilizing mocked pigpio.
- **Integration**: Refactored `ninja_core/src/ninja_core/robot_sound.py` to import `NOTES` and `EMOTION_SOUNDS` directly from `pi0buzzer.notes` (single source of truth), preserving the `RobotSoundPlayer` interface for backward compatibility.
- **Files Modified**: `pi0buzzer/` (full directory replacement), `ninja_core/src/ninja_core/robot_sound.py`, `ProjectUpgradePlan.md`, `pi0buzzer/RebuildPlan.md`.
- **Validation**: `uv run ruff check` passed clean on all files. 61 pytest checks succeeded. `buzzer.json` configuration tested locally via the CLI tools.

## 2026-02-25: InstallationGuide.md — Reorganize Calibration Sequence ✓
- **Action**: Reorganized sections 7 and 8 in all three languages (English, Japanese, Chinese) so all component setup/calibration happens **before** `ninja_core config import`.
- **New Flow**: 7.1 Display Setup → 7.2 Buzzer Setup → 7.3 Distance Sensor Test → 7.4 Servo Calibration → 7.5 Gemini API Key → **7.6 Import All Configs** → 8 System Integration Testing
- **Rationale**: `ninja_core config import` reads from `servo.json`, `buzzer.json`, and `pi0disp/display.json`. These files must exist and be verified before import.
- **Files Modified**: `InstallationGuide.md` (English, Japanese, Chinese sections)

## 2026-02-25: Fix Display Integration — GPIO Pin Mismatch ✓
- **Root Cause**: `ninja_core` `DisplayConfig` defaults were DC=14, RST=15, BLK=16. Actual hardware uses DC=18, RST=19, BLK=20. `pi0disp` standalone worked because it reads its own `display.json` (correct pins). HAL used `config.json` defaults (wrong pins) → backlight and D/C signals went to wrong GPIO → blank display.
- **Fix**:
  - **`config.py`**: Changed `DisplayConfig` defaults to `None` (forces explicit configuration). Added `display.json` import to `import_and_update_config()` (same pattern as servo.json/buzzer.json).
  - **`hal.py`**: `_init_display()` now auto-reads `pi0disp/display.json` as fallback when config pins are None. Logs actual pin values being used.
  - **`InstallationGuide.md`**: Updated wiring table (configurable pins), config import output (shows display.json), troubleshooting (GPIO mismatch).
- **Files Modified**: `ninja_core/src/ninja_core/config.py`, `ninja_core/src/ninja_core/hal.py`, `InstallationGuide.md`
- **Validation**: ruff check passed.

## 2026-02-25: Fix Display Integration — Robustness Improvements ✓
- **Root Cause**: Exhaustive code audit confirmed V2 driver's low-level SPI/color code is identical to old driver. Blank display caused by integration-layer issues: (1) V2's delta rendering and window caching introduced silent failure modes absent from old brute-force driver, (2) `facial_expressions.py` silently swallowed ALL exceptions including display errors, (3) HAL never verified display after init, (4) no RGB mode enforcement.
- **Fix**:
  - **`driver.py`**: Switched to full-frame rendering (no delta), removed window caching (RAMWR always sent), added `.convert('RGB')` safety, added logging
  - **`facial_expressions.py`**: Replaced `except (AttributeError, Exception): break` with `log.error()` + stack trace
  - **`hal.py`**: Added `display.clear((0,0,0))` verification after init with detailed logging
  - **`web_server.py`**: Added diagnostic prints around QR/face display fallback paths
- **Files Modified**: `pi0disp/src/pi0disp/core/driver.py`, `ninja_core/src/ninja_core/facial_expressions.py`, `ninja_core/src/ninja_core/hal.py`, `ninja_core/src/ninja_core/web_server.py`, `pi0disp/tests/test_driver.py`
- **Validation**: ruff check passed, 54/54 pytest tests passed.

## 2026-02-25: Fix Display Integration — Rotation Default Mismatch ✓
- **Root Cause**: Old `pi0disp_bak` driver defaulted to `rotation=90` (landscape 320×240), but the new V2 driver defaulted to `rotation=0` (portrait 240×320). Since `hal.py` didn't pass a rotation parameter, the display initialized in wrong orientation — QR codes and face expressions appeared rotated 90°.
- **Fix**: Changed default rotation from 0 to 90 in driver, added `rotation` field to `DisplayConfig`, and passed it from HAL to the ST7789V constructor. User can change rotation via `pi0disp init`.
- **Files Modified**: `pi0disp/src/pi0disp/core/driver.py`, `pi0disp/src/pi0disp/config/config_manager.py`, `ninja_core/src/ninja_core/config.py`, `ninja_core/src/ninja_core/hal.py`, `pi0disp/tests/test_driver.py`
- **Validation**: ruff check passed, 54/54 pytest tests passed.

## 2026-02-25: pi0disp V2 — Full Library Rebuild ✓
- **Action**: Built the new pi0disp library from scratch following `pi0disp/RebuildPlan.md`.
- **Details**:
    - **Phase 1 — Scaffold**: Created `pyproject.toml`, `display.json`, package structure with 4 submodules (core/, config/, effects/, cli/).
    - **Phase 2 — Core Driver**: `driver.py` with thread-safe SPI (`threading.Lock()`), smart delta rendering (`PIL.ImageChops.difference()`), PWM brightness, full Actuator ABC, context manager.
    - **Phase 3 — Config Manager**: `config_manager.py` with `init_config()` interactive wizard, display profiles (ST7789V 2.8", Waveshare 2.0"), CRUD operations, export/import.
    - **Phase 4 — Effects**: `text_ticker.py` scrolling text with multilingual font support (EN/JA/ZH-TW).
    - **Phase 5 — CLI**: 7 commands (init, image, text, demo, info, clear, brightness) + `display-tool` interactive menu + `config` subgroup.
    - **Renderer**: `renderer.py` with `ColorConverter` (numpy LUT RGB→RGB565) and `RegionOptimizer` (clamp/merge dirty rects).
    - **Tests**: 54 unit tests (all passing) covering driver, renderer, and config. Thread-safety tests included.
    - **Integration**: Updated `DRIVER_REGISTRY` in `hal.py` from `pi0disp.disp.st7789v` to `pi0disp.core.driver`.
    - **Bug Fixed**: IndexError in `RegionOptimizer.merge_regions()` pop order during aggressive merging.
    - **Lint**: ruff check clean (0 errors).
- **Related Files**: `pi0disp/` (entire new library), `ninja_core/src/ninja_core/hal.py`.

## 2026-02-25: pi0disp V2 — Documentation Update ✓
- **Action**: Updated all project documentation to reflect the pi0disp V2 rebuild.
- **Details**:
    - `pi0disp/README.md`: Full rewrite (370+ lines). Added comprehensive API reference (ST7789V, ConfigManager, TextTicker), all CLI commands with examples, Raspberry Pi testing guide (8 steps), troubleshooting table, architecture diagram.
    - `DevelopmentGuide.md`: Rewrote section 3.4 with V2 module paths, full API tables, `execute()` command keys, ConfigManager/TextTicker docs. Updated file tree, dependency graph, V5.2.4 change summary. Added `pi0disp init` to Required Setup.
    - `InstallationGuide.md`: Updated display test sections in EN/JA/ZH-TW. Replaced `ball_anime` with `demo`. Added `init`, `brightness`, `text`, `info --health-check` test steps. Updated display troubleshooting with `info --health-check` and `init`.
- **Related Files**: `pi0disp/README.md`, `DevelopmentGuide.md`, `InstallationGuide.md`.

## 2026-02-16: Comprehensive Documentation Audit & Refinement ✓
- **Action**: detailed audit of `DevelopmentGuide.md`, `InstallationGuide.md`, and `ProjectUpgradePlan.md` against actual codebase (`pi0servo`, `pi0vl53l0x`).
- **Details**:
    - **DevelopmentGuide.md**: Corrected wrong module names (`multi_servos.py`, `calculator.py`), function signatures (`move_all_sync`, `calculate_duration`), return types, and `ServoCalibration` (7 fields). Added missing method docs.
    - **InstallationGuide.md**: Replaced invalid `uv run pi0servo servo ...` commands with correct `move` or `cmd` syntax across English, Japanese, and Chinese sections.
    - **ProjectUpgradePlan.md**: Updated library inventory to reflect current file structure, refreshed DRIVER_REGISTRY paths, marked pi0servo/pi0vl53l0x phases as Complete, and updated "Last updated" date.
- **Related Files**: `DevelopmentGuide.md`, `InstallationGuide.md`, `ProjectUpgradePlan.md`.

## 2026-02-16: pi0vl53l0x — CLI Refinement & README Restructuring ✓
- **Action**: Restored individual CLI commands alongside `sensor-tool` TUI; restructured README for standalone Pi usage.
- **Details**:
    - Restored individual CLI commands (`get`, `performance`, `calibrate`, `test`, `status`, `config show/export/import`) to `sensor_tool.py` alongside the interactive `sensor-tool` TUI.
    - Added `_create_sensor()` helper for shared sensor initialization across individual commands.
    - Restructured `README.md`: Installation focuses on standalone Raspberry Pi with explicit `uv` setup instructions. CLI sections (interactive + individual commands) moved above Quick Start. All command examples use `uv run` prefix.
    - Fixed stale installation bug: `sensor-tool` command was not found on Pi due to cached old `sensor_tool.py` without the `sensor-tool` subcommand.
- **Related Files**: `pi0vl53l0x/src/pi0vl53l0x/cli/sensor_tool.py`, `pi0vl53l0x/README.md`.

## 2026-02-16: pi0vl53l0x Bug Fix — Entry Point & pigpio Import ✓
- **Action**: Fixed two critical bugs in pi0vl53l0x CLI and documented `uv sync` installation.
- **Details**:
    - Fixed `ImportError: cannot import name 'cli'` — root `pyproject.toml` referenced `:cli` but `__main__.py` only exported `main`. Now exports both.
    - Aligned `pi0vl53l0x/pyproject.toml` entry point to `:cli` (matching root convention).
    - Guarded top-level `VL53L0X` import in `__init__.py` for environments without pigpio.
    - Improved `_connect_pigpio()` error message with `uv sync --extra pi` instructions.
    - Added `uv sync` (recommended) alongside `uv pip install -e .` in `InstallationGuide.md` Step 6.3 (EN/JA/ZH-TW).
    - Updated `pi0vl53l0x/README.md` installation section with `uv sync --extra pi`.
- **Related Files**: `pi0vl53l0x/src/pi0vl53l0x/__main__.py`, `pi0vl53l0x/src/pi0vl53l0x/__init__.py`, `pi0vl53l0x/src/pi0vl53l0x/cli/sensor_tool.py`, `pi0vl53l0x/pyproject.toml`, `InstallationGuide.md`, `pi0vl53l0x/README.md`.

## 2026-02-15: InstallationGuide.md — pi0vl53l0x V2 Content Refinement ✓
- **Action**: Expanded all pi0vl53l0x sections in `InstallationGuide.md` (EN/JA/ZH-TW) to reflect V2 CLI.
- **Details**:
    - Step 7.2 (Test Distance Sensor): Added `test`, `status`, and `calibrate` commands.
    - Test 8.4 (Performance): Added `status` and `config show` commands.
    - Troubleshooting (Distance sensor not responding): Added `test`/`status` diagnostics and power-cycle guidance.
- **Related Files**: `InstallationGuide.md`.

## 2026-02-15: pi0vl53l0x V2 Documentation Update ✓
- **Action**: Updated all project documentation to reflect the pi0vl53l0x V2 rebuild.
- **Details**:
    - `DevelopmentGuide.md`: Rewrote section 3.3 (new I2C/sensor/config/CLI modules, full API reference tables, exception contract, usage examples). Updated file tree, version to 5.2.3, added V5.2.3 change summary, updated dependency graph.
    - `README.md`: Updated version to 5.2.3 and pi0vl53l0x V2 status in EN/JA/ZH-TW.
    - `pi0vl53l0x/README.md`: Full rewrite with directory structure, installation, Python API examples, complete API reference, 8 CLI commands with examples, test coverage table, and ASCII architecture diagram.
- **Related Files**: `DevelopmentGuide.md`, `README.md`, `pi0vl53l0x/README.md`.

## 2026-02-14: pi0vl53l0x V2 Library Rebuild — COMPLETE ✓
- **Action**: Full rewrite of the VL53L0X distance sensor driver from scratch.
- **Details**:
    - **Phase 1 - Scaffold & I2C**: Created `core/i2c.py` with thread-safe `threading.Lock`, exponential backoff retry (10→20→50ms), bus recovery, big-endian word handling. `registers.py` with ~60 semantic constants (22 tests).
    - **Phase 2 - Sensor Driver**: Created `core/sensor.py` with hardened init (firmware boot polling up to 1.0s), fixed V2 offset bug (raw_value now truly raw), defined exception contract (`I2CError`/`TimeoutError`/`RuntimeError`), async support, health check, reinitialize. `driver.py` backward-compat shim (22 tests).
    - **Phase 3 - Config Manager**: Created `config/config_manager.py` with load/save, export/import, corrupt JSON handling, project-relative default path (16 tests).
    - **Phase 4 - CLI Module**: Created `cli/sensor_tool.py` with 8 commands: `get`, `performance`, `calibrate`, `test`, `status`, `config show/export/import`. English output, lazy `pigpio` import.
    - **Phase 5 - Integration**: Verified backward compat with `ninja_core/hal.py` (`pi0vl53l0x.driver.VL53L0X`). Updated `README.md` with full docs.
- **Key Fixes**:
    - **V2 offset bug**: `get_data()` now stores true raw value before offset correction
    - **Reboot bug**: Firmware boot polling with configurable timeout prevents "returns 0"
    - **Thread safety**: All I2C access serialized via `threading.Lock`
- **Validation**: 60/60 tests pass, ruff lint clean.
- **Related Files**: `pi0vl53l0x/src/pi0vl53l0x/*`, `pi0vl53l0x/tests/*`, `pi0vl53l0x/README.md`.

## 2026-02-09: Movement Fluidity Enhancement ✓
- **Issue**: Multi-servo recorded movements feel mechanical with abrupt transitions.
- **Root Cause**: Each step uses `ease_in_out_cubic` independently, creating stop-start pattern.
- **Solution**: Position-aware transition easing:
    - Single step: `ease_in_out_cubic` (full curve)
    - First step: `ease_in_cubic` (accelerate only)
    - Middle steps: `linear` (constant velocity)
    - Last step: `ease_out_cubic` (decelerate to stop)
- **Modified Files**:
    - `ninja_core/src/ninja_core/movement_controller.py`

## 2026-02-09: Ninja Core Servo & Shutdown Fixes ✓
- **Issues Fixed**:
    1. Servo limpness during ninja_core server operation
    2. Missing wake-up behavior (servos not centering on user connect)
    3. Shutdown error traceback on Ctrl+C
- **Root Causes**:
    - `MovementController.move_servos()` didn't pass `force=True` to `move_all_sync()`
    - `trigger_welcome()` only played face/sound, no servo centering
    - `sigint_handler()` raised `KeyboardInterrupt` conflicting with uvloop
- **Fixes**:
    1. Added `force=True` to `move_all_sync()` in movement_controller.py
    2. Added servo centering in `trigger_welcome()` on user connection
    3. Added servo priming at server startup in `lifespan()`
    4. Replaced `raise KeyboardInterrupt` with `sys.exit(0)` for clean shutdown
- **Modified Files**:
    - `ninja_core/src/ninja_core/movement_controller.py`
    - `ninja_core/src/ninja_core/web_server.py`

## 2026-02-09: Servo Limpness Prevention ✓
- **Issue**: Servos occasionally become limp and unresponsive during movements.
- **Root Cause**: `move_all_sync()` skips PWM updates when `distance < 0.1°`, combined with stale `last_angle` tracking.
- **Solutions Implemented**:
    1. Added `refresh()` and `ensure_active()` methods to `Servo` class
    2. Added `force` flag to `move_all_sync()` to bypass skip-if-negligible logic
    3. Added skip logging for debugging (`logger.debug()`)
    4. Added `refresh_all()` and `ensure_all_active()` to `ServoGroup`
    5. Updated `servo_tool.py` to reuse persistent `ServoGroup`, preserving `last_angle` state
- **Modified Files**:
    - `pi0servo/src/pi0servo/core/servo.py`
    - `pi0servo/src/pi0servo/core/multi_servos.py`
    - `pi0servo/src/pi0servo/cli/servo_tool.py`
- **Tests**: All 82 unit tests passed
## 2026-02-09: Fix First-Run Servo Initialization ✓
- **Issue**: After Pi restart, servos didn't react on first CLI run; auto-center failed.
- **Root Cause**: `move_all_sync()` skips movement when `distance < 0.1`. On first run, `last_angle=None` and `get_pulse()=0`, so code falls back to `angle_center=0`. Since target is also 0, movement was skipped.
- **Fix**: Use `center_all()` (direct PWM) instead of `move_all_sync()` for startup centering.
- **Modified Files**:
    - `pi0servo/src/pi0servo/cli/servo_tool.py` - Replaced `move_all_sync()` with `center_all()`
    - `ninja_core/src/ninja_core/movement_cli.py` - Use direct `hal.servos.center_all()`

## 2026-02-09: Auto-Center Servos on CLI Start/Quit ✓
- **Action**: Added automatic servo centering (0°) when starting and quitting CLI tools.
- **Changes**:
    - On tool startup: all calibrated servos move to 0°
    - On tool exit: all servos center before shutdown
- **Modified Files**:
    - `pi0servo/src/pi0servo/cli/servo_tool.py`
    - `ninja_core/src/ninja_core/movement_cli.py`

## 2026-02-09: Servo Smoothness Optimization ✓
- **Action**: Reduced jittering by increasing update frequency and adding cubic easing.
- **Changes**:
    - Step interval: 20ms → 10ms (50Hz → 100Hz)
    - Added 3 cubic easing functions: `ease_in_cubic`, `ease_out_cubic`, `ease_in_out_cubic`
    - Default easing: `ease_in_out` → `ease_in_out_cubic`
- **Modified Files**:
    - `pi0servo/src/pi0servo/motion/easing.py`
    - `pi0servo/src/pi0servo/motion/__init__.py`
    - `pi0servo/src/pi0servo/core/multi_servos.py`
    - `ninja_core/src/ninja_core/movement_controller.py`

## 2026-02-09: Default Easing Changed to ease_in_out ✓
- **Action**: Changed default servo easing from `ease_out` to `ease_in_out`.
- **Reason**: Provides smoother motion at both start and end of movements.
- **Modified Files**:
    - `pi0servo/src/pi0servo/core/multi_servos.py` - All method defaults
    - `ninja_core/src/ninja_core/movement_controller.py` - `move_servos()` call

## 2026-02-08: Phase 12 - Documentation Update ✓
- **Action**: Updated all documentation for pi0servo V2 integration.
- **Changes**:
    - Deleted `pi0servo_bak` folder.
    - Updated `README.md` version to 5.2.1 in all language sections.
    - Updated `DevelopmentGuide.md` file structure (pi0servo now has cli, config, core, motion, parser folders).
    - Replaced Section 3.5 pi0servo API docs with new ServoGroup/ConfigManager/MotionPlanner API.
    - Updated `ninja_core/README.md` driver registry (ServoGroup instead of MultiServo).
- **Note**: `pi0servo/tests/` folder contains valid unit tests and was kept.

## 2026-02-08: Phase 11 - First Run Servo Issue ✓
- **Issue**: Servo 23 had no reaction on first movement-tool run after calibrating pin 23.
- **Root Cause**: After calibration, `config` was reloaded but HAL's `ServoGroup` kept old pin list. New pins (e.g., 23) not included until restart.
- **Solution**: After calibration, turn off old servos and reinitialize HAL with new config:
    - `hal.servos.off()` - release old PWM
    - `hal.config = config` - update config reference
    - `hal._init_servos()` - create new ServoGroup with all pins
- **Related Files**: `movement_cli.py`, `hal.py`.

## 2026-02-08: Phase 10 - Movement Tool Health Check ✓
- **Issue**: `edit_sequence_menu` threw `TypeError: dict - int` when editing/inserting steps.
- **Root Cause**: `parse_movement_command` returns `{pin: {"angle": X, "speed": Y}}`, but edit/insert stored this directly as `moves` instead of extracting angles.
- **Solution**:
    - Added `extract_movement_data()` helper to split parsed moves into `(angles_dict, per_servo_speeds_dict)`.
    - Fixed Edit Step, Insert Step to use helper and store separate `moves` and `per_servo_speeds`.
    - Fixed Preview to pass `per_servo_speeds` to `move_servos`.
- **Related Files**: `movement_cli.py`.

## 2026-02-08: Phase 9 - Fix Silent Failure ✓
- **Issue**: movement-tool showed no reaction when entering servo commands.
- **Root Cause**: `ServoArrayWrapper` was missing methods that `MovementController` calls:
    - `move_all_sync()` - per-servo speed movement
    - `pins` property - ordered GPIO pin list
    - `get_all_angles()` - current angle state
    - `move_all_angles()` - instant movement
- **Solution**: Added wrapper methods to `ServoArrayWrapper` that proxy to `_multi_servo`.
- **Related Files**: `api_wrappers.py`.

## 2026-02-08: Phase 8 - Per-Servo Speed Execution ✓
- **Action**: Refactored `MovementController` to use pi0servo's velocity-based motion.
- **Root Cause**: Old implementation used manual interpolation with single global duration.
- **Solution**:
    - `move_servos()` now calls `move_all_sync(speed_mode=list[str])` for per-servo speeds.
    - Each servo calculates its own duration: `distance / (speed_limit × mode_factor)`.
    - Faster servos reach target before slower ones within the same movement.
- **Flow**: Parser → Recording → Storage (`per_servo_speeds`) → Execution
- **Related Files**: `movement_controller.py`, `movement_cli.py`.

## 2026-02-08: Phase 7 Refinements - Speed & Parser ✓
- **Action**: Added speed field import and per-servo speed parsing.
- **Issue 1 - Speed not imported**:
    - `ServoCalibration` model now includes `speed: int = 80` field.
    - `import_and_update_config()` now maps `speed` from servo.json.
- **Issue 2 - Per-servo speed parsing**:
    - `parse_movement_command()` now parses suffixes: `22:45S`, `23:-30F`.
    - Returns `{pin: {"angle": value, "speed": str|None}}` format.
    - `record_new_movement()` stores `per_servo_speeds` in sequence.
- **Command Format** (matches pi0servo servo-tool):
    - Global: `F_22:45/23:-30` → All servos use Fast speed
    - Per-servo: `22:45S/23:-30F` → Pin 22 Slow, Pin 23 Fast
    - Mixed: `F_22:45/23:-30S` → Global Fast, but Pin 23 overrides to Slow
- **Related Files**: `ninja_core/config.py`, `ninja_core/movement_cli.py`.

## 2026-02-08: Fixed pi0servo Integration Issues ✓
- **Action**: Fixed config import compatibility between pi0servo and ninja_core.
- **Root Cause**: 
    - pi0servo saves `servo.json` as dict with `pulse_min/center/max` field names.
    - ninja_core `import_and_update_config()` only handled list format and used `min_pulse/center_pulse/max_pulse`.
- **Solution**: 
    - Updated `config.py` to handle both dict (pi0servo) and list (legacy) formats.
    - Added field name mapping: `pulse_min` → `min_pulse`, `pulse_center` → `center_pulse`, etc.
- **Commands Verified**:
    - `uv run ninja_core config import` ✓ (alias for import-all)
    - `uv run ninja_core config import-all` ✓
    - `uv run ninja_core movement-tool` ✓ (not `ninja-cli movement`)
- **Related Files**: `ninja_core/config.py`.

## 2026-02-08: pi0servo Integration Phase 3 & 4 ✓
- **Action**: Completed angle standardization and velocity-based movement.
- **Phase 3 - Angle Standardization (±90°)**:
    - Updated `api_wrappers.py`: ServoWrapper and ServoArrayWrapper now use ±90° directly.
    - Removed all 0-180 → ±90 conversions (breaking change for Blockly programs).
    - Center position now 0° (was 90° in old API).
- **Phase 4 - Movement-Tool Enhancement**:
    - Updated `movement_controller.py`: Replaced fixed `duration_map` with `calculate_duration()`.
    - Uses physics-based velocity calculation (SG90 spec: 600°/sec).
    - Duration now depends on actual travel distance and speed mode (F/M/S).
- **Verification**: Ruff lint passed for both files.
- **Related Files**: `ninja_core/api_wrappers.py`, `ninja_core/movement_controller.py`.

## 2026-02-08: pi0servo Integration into ninja_core - Phase 1 ✓
- **Action**: Integrated rebuilt `pi0servo` library into `ninja_core` HAL.
- **Breaking Changes**:
    - **DRIVER_REGISTRY**: Updated to point to `pi0servo.core.multi_servos.ServoGroup` (was `multi_servo.MultiServo`).
    - **HAL init**: Modified `_init_servos()` to use `ConfigManager` for pre-loading calibrations.
    - Calibrations now passed as `dict[int, ServoCalibration]` instead of `conf_file` path.
- **Legacy Compatibility**:
    - Added `move_all_angles()` method to `ServoGroup` for instant movement.
    - Added `get_all_angles()` method to `ServoGroup` for reading current state.
    - Added `servo` property to `ServoGroup` for list-style access.
    - Existing `move_all_angles_sync()` wrapper maintained for duration-based calls.
- **Verification**: Ruff lint passed for both `hal.py` and `multi_servos.py`.
- **Related Files**: `ninja_core/hal.py`, `pi0servo/core/multi_servos.py`.

## 2026-02-08: Fixed GPIO Initialization Error ✓
- **Action**: Fixed critical error `'GPIO is not in use for servo pulses'` that occurred after reboot.
- **Root Cause**: `get_servo_pulsewidth()` throws exception when GPIO has no PWM initialized (after reboot).
- **Solution**:
    - Wrapped `get_pulse()` in try/except to return 0 on pigpio error.
    - Changed default calibration to safe values (all pulses = 1500) to prevent unexpected servo movement.
    - Added `HARDWARE_PULSE_MIN/MAX` constants (500/2500) to `calib.py` for calibration TUI (separate from default calibration).
- **Documentation**:
    - Added calibration CAUTION warning to README Quick Start.
    - Clarified `uv sync` installation (no manual venv activation needed).
    - Added NOTE about default uncalibrated behavior in Configuration section.
- **Tests**: Added 2 new tests for exception handling, updated 6 tests for new defaults. **82/82 passed**.
- **Related Files**: `core/servo.py`, `cli/calib.py`, `README.md`, `tests/test_core.py`, `tests/test_config.py`.

## 2026-02-08: Per-Servo Speed Control Implemented ✓
- **Action**: Added support for individual servo speed overrides in `movement-tool` commands.
- **Details**:
    - **Parser**: Updated `parse_command` to detect speed suffixes (e.g., `45F`, `45S`).
    - **Logic**: Updated `move_all_sync/async` to apply per-servo duration scaling.
    - **Validation**: Enforced strict regex matching to prevent invalid command parsing.
- **Documentation**: Updated `README.md` with new command syntax and examples.
- **Verification**: Added unit tests for new parser features (27/27 passed).
- **Related Files**: `parser/command.py`, `core/multi_servos.py`, `README.md`.

## 2026-02-08: Servo-Tool Movement Control Fixes ✓
- **Action**: Fixed 3 user-reported issues from servo-tool testing.
- **Issue 1: Calibration Not Refreshing**:
    - Added `manager.load()` after `CalibApp.main()` returns in `servo_tool.py`.
    - New calibration values now apply immediately without restarting servo-tool.
- **Issue 2: Speed Control Not Working**:
    - Refactored `move_all_sync()` and `move_all_async()` to use **per-servo timing**.
    - Each servo now moves at its own calibrated speed (faster servos finish first).
    - Changed from step-based to time-based movement loop (`time.monotonic()`).
- **Issue 3: Continuous Input Mode**:
    - Rewrote `quick_move()` and `single_move()` with continuous input loops.
    - Users can enter multiple commands until pressing 'q' to return to menu.
- **Verification**: 74/74 tests passing, linter clean.
- **Related Files**: `servo_tool.py`, `multi_servos.py`.

## 2026-02-10: pi0servo Audit Issues Fixed ✓
- **Action**: Fixed all issues identified in the pi0servo code audit.
- **P0 Critical Bugs**:
    - Fixed `_configs` attribute errors in `config_cmd.py` and `servo_tool.py` (replaced with `get_all_calibrations()` method).
    - Added missing `_to_dict()`, `save_to()`, and `load_from()` methods to `ConfigManager`.
- **P1 Moderate Issues**:
    - Added `finally` block in `servo_tool.py` for proper `pi.stop()` cleanup.
    - Added division-by-zero guards in `servo.py` `angle_to_pulse()` and `pulse_to_angle()`.
    - Added pulse validation warning in `set_pulse()` for out-of-range values.
- **User-Reported Issues**:
    - Added **speed control** (`+`/`-` keys) to calibration TUI for adjusting per-servo speed limits.
    - Verified easing implementation is correct in `multi_servos.py` using `ease_out` by default.
    - Added **Set Speed menu option** to `servo-tool` (option 4) for dedicated speed limit setting.
- **Documentation**:
    - Completely rewrote `pi0servo/README.md` with `servo-tool` as primary interface.
    - Added detailed calibration guide with speed control, easing explanation, and command reference.
    - Added Python API section for setting speed limits programmatically.
- **Verification**: `uv run ruff check` passed for all source files.
- **Related Files**: `config_manager.py`, `config_cmd.py`, `servo_tool.py`, `calib.py`, `servo.py`, `README.md`.

## 2026-02-08: pi0servo V5 Refinement - Bugs Fixed ✓
- **Action**: Fixed 4 user-reported bugs + 4 audit gaps to complete the pi0servo library to 100%.
- **P0 Bug Fixes**:
    - **CLI `move` negative angles**: Changed angle type from `float` to `str` to prevent Click parsing `-90` as option flag.
    - **CLI `cmd` TypeError**: Fixed `config_path` invalid parameter by loading calibrations via `ConfigManager`.
    - **CLI `calib` not interactive**: Rewrote as full TUI using `blessed` library with keyboard navigation (Tab/Up/Down/Enter).
- **P1 Backward Compatibility**:
    - Added `MultiServo = ServoGroup` alias in `__init__.py` for ninja_core.
    - Added `move_all_angles_sync()` legacy wrapper method in `ServoGroup`.
- **P1 Documentation**:
    - Updated `pi0servo/README.md` with "calibration-first" Quick Start section.
- **Phase 2 Enhancements (Completed)**:
    - **Interactive Tool**: Added `servo-tool` CLI with menu for quick testing and calibration.
    - **Config Management**: Added `pi0servo config` command for export/import.
    - **Unit Tests**: Added comprehensive tests for `ConfigManager` (13 tests passing).
- **Linting**: Fixed 7 lint errors (unused imports, unsorted imports, f-string).
- **Related Files**: `cli/servo_tool.py`, `cli/config_cmd.py`, `tests/test_config.py`.

## 2026-02-07: pi0servo V5 Rebuild COMPLETE ✓
- **Action**: Completed full pi0servo library rebuild following `RebuildPlan.md`.
- **Details**:
    - **Phase 0 - Scaffold**: Created project structure, `pyproject.toml`, `conftest.py` with mock pigpio.
    - **Phase 1 - Motion**: Implemented easing functions (`linear`, `ease_out`, `ease_in`, `ease_in_out`) and velocity-based duration calculations (17 tests).
    - **Phase 2 - Parser**: Implemented command parsing for `[SPEED_]PIN:ANGLE[/PIN:ANGLE...]` format (21 tests).
    - **Phase 3 - Core**: Implemented `Servo` (single servo with calibration), `ServoGroup` (multi-servo with abort mechanism via `threading.Event` and `asyncio.Event`) (23 tests).
    - **Phase 4 - Config**: Implemented `ConfigManager` for JSON-based calibration persistence with `speed` field (13 tests).
    - **Phase 5 - CLI**: Implemented `cmd`, `move`, `calib`, `status` commands with Click framework.
    - **Phase 6 - Integration**: Finalized exports in `__init__.py`, all 74 tests passing.
- **Key Features**:
    - Non-blocking servo control with abort mechanism
    - Velocity-based movement duration calculation
    - Per-servo speed limits (0-100%)
    - Easing curves for smooth motion profiles
    - Unified command format compatible with movement-tool
    - Optional ninja_utils integration (fallback to standard logging)
- **Validation**: `uv run pytest tests/ -v` → 74 passed, `uv run python -m pi0servo --help` works.
- **Related Files**: `pi0servo/src/pi0servo/*`, `pi0servo/tests/*`, `pi0servo/RebuildPlan.md`.

## 2026-02-07: pi0servo Rebuild Phase 0 - Project Scaffold COMPLETE
- **Action**: Created new pi0servo project structure from scratch.
- **Details**:
    - Created directory structure: `src/pi0servo/{motion,parser,core,config,cli}`, `tests/`.
    - Created `pyproject.toml` with dependencies: pigpio, click, blessed, ninja_utils.
    - Created `LICENSE` (MIT), `README.md` with usage documentation.
    - Created `__init__.py` (v1.0.0) and `__main__.py` (Click CLI entry point).
    - Created `tests/conftest.py` with mock pigpio fixture for PC/Mac development.
    - All modules have placeholder `__init__.py` files.
- **Validation**: `uv sync` passed, import test (v1.0.0) passed, CLI help works, lint clean.
- **Related Files**: `pi0servo/pyproject.toml`, `pi0servo/src/pi0servo/*`, `pi0servo/tests/conftest.py`.

## 2026-02-07: pi0servo Documentation Modularization
- **Action**: Extracted `pi0servo` rebuild plan into a dedicated `RebuildPlan.md` file.
- **Details**:
    - Created `pi0servo/RebuildPlan.md` with the complete step-by-step implementation guide.
    - Added new sections for **abort mechanism** (`threading.Event` + `asyncio.Event`).
    - Added new sections for **native async support** (`move_to_async()`).
    - Updated `ProjectUpgradePlan.md` Appendix A to reference the new file.
    - Updated Appendix B with link to the new modular document.
- **Backup**: Old `pi0servo` folder renamed to `pi0servo_bak`.
- **Related Files**: `pi0servo/RebuildPlan.md`, `ProjectUpgradePlan.md`.

## 2026-01-25: Graceful Shutdown Animation
- **Action**: Implemented shutdown animation sequence for server termination.
- **Details**:
    - Created `_perform_shutdown_animation()` helper function in `web_server.py`.
    - Sequence: "sleepy" face + "sleepy" sound (parallel) → "Poweroff" pose (blocking).
    - Integrated with Ctrl+C handler (`emergency_cleanup`) for SIGINT shutdown.
    - Integrated with `/api/system/shutdown` endpoint for web interface poweroff.
    - All servo movements complete before system shutdown proceeds.
- **Verification**: `ruff check` passed.
- **Related Files**: `web_server.py`, `config.json` (Poweroff movement definition).
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

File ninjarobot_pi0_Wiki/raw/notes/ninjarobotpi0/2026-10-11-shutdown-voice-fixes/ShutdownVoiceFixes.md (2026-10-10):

# Server shutdown and browser voice regression repair

Date: 2026-10-11 (Asia/Tokyo). User-authorized regression fixes following the model adapter implementation. This is new English source evidence for owner manual ingestion and review; registered originals, canonical pages, semantic review records and the knowledge map are unchanged.

## 1. Scope of validation

Restore the configured Poweroff rest pose on ordinary `ninja_core server` exit and restore browser microphone input independently of cloud model selection. Preserve provider-specific direct audio-file capability checks. Keep servo drivers, calibration, GPIO mapping, cloud adapters and credentials unchanged.
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

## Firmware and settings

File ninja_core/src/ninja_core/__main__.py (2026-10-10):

import click

from .config import import_and_update_config, set_api_key, set_robot_name, set_robot_type
from .gemini_models import GeminiModelDiscoveryError
from .gemini_runtime import GeminiRuntimeError
from .init_tool import configure_gemini_api_key, run_init_tool

from .provider_setup import configure_ai_model
from .providers.base import ProviderError

from .movement_cli import run_cli as run_movement_cli


@click.group()
def main():
    """Command-line interface for NinjaRobotV4 core application."""

    pass


@main.command("movement-tool")
def movement_tool():
    """Launch the interactive CLI tool for recording and editing servo movements."""

    run_movement_cli()


@main.command("init-tool")
def init_tool():
    """Launch the guided NinjaRobotV5 setup menu."""

    run_init_tool()


@main.group()
def config():
    """Manage the robot's configuration."""

    pass


@config.command("import-all")
@click.pass_context
def import_all(ctx):
    """
    Imports settings from hardware files (e.g., servo.json) into the main
    config.json, or applies defaults if files are missing.
    """
    import_and_update_config()


# Alias: 'import' -> 'import-all' for convenience
@config.command("import")
def import_config():
    """Alias for 'import-all'. Imports servo.json and buzzer.json into config.json."""
    import_and_update_config()


@config.command("set-key")
@click.argument("service")
@click.argument("key")
def set_key(service, key):
    """
    Set an API key for a service (e.g., gemini).

    Usage: ninja_core config set-key gemini YOUR_API_KEY
    """
    if service == "gemini":
        try:
            configure_gemini_api_key(key)
        except (GeminiModelDiscoveryError, GeminiRuntimeError, ValueError) as exc:
            raise click.ClickException(str(exc)) from exc
        return

    if service in ("google", "openai", "anthropic", "ollama"):
        try:
            configure_ai_model(service, api_key=key)
        except (ProviderError, GeminiModelDiscoveryError, GeminiRuntimeError) as exc:
            raise click.ClickException(str(exc)) from None
        return
    set_api_key(service, key)


@config.command("select-model")
def select_model():
    """Select cloud provider, enter a hidden key, and validate a model."""
    try:
        configure_ai_model()
    except (ProviderError, GeminiModelDiscoveryError, GeminiRuntimeError) as exc:
        raise click.ClickException(str(exc)) from None


@config.command("set-name")
@click.argument("name", nargs=-1)
def set_name(name):
    """
    Set the BLE advertising name shown during Bluetooth discovery.

    Usage: ninja_core config set-name "Classroom Ninja 1"
    """
    set_robot_name(" ".join(name))


@config.command("set-type")
@click.argument("robot_type")
def set_type(robot_type):
    """
    Set the NinjaRobot type used by Code IDE profile synchronization.

    Usage: ninja_core config set-type humanoid
    """
    set_robot_type(robot_type)


@main.command("chat")
def chat():
    """
    Start an interactive text chat with the Ninja Agent.
    This initializes the robot hardware and allows you to type commands.
    """
    import asyncio
    import time
    import threading
    from .config import load_config
    from .hal import HardwareAbstractionLayer
    from .ninja_agent import NinjaAgent
    from .action_library import ActionLibrary
    from .facial_expressions import AnimatedFaces
    from .robot_sound import RobotSoundPlayer
    from .perception import DistanceMonitor
    from .movement_controller import MovementController, EmergencyStop

    async def run_chat():
        print("Initializing NinjaRobot Hardware...")
        config = load_config()
        hal = HardwareAbstractionLayer(config)
        hal.initialize()
        
        # Initialize Distance Monitor
        distance_monitor = DistanceMonitor(hal)
        distance_monitor.start_continuous(interval=0.05)
        
        # Initialize Controllers (declare outside try for finally access)
        faces = None

        try:
            print("Initializing AI Agent...")
            action_library = ActionLibrary()
            agent = NinjaAgent(config, action_library=action_library)
            print(f"Using {agent.provider_name} model: {agent.model_name}")
            
            # Initialize Controllers
            faces = AnimatedFaces(hal)
            sound = RobotSoundPlayer(hal)
            movement = MovementController(hal, config)

            print("\n--- Ninja Agent Ready ---")
            print("Type 'exit' or 'quit' to stop.")
            
            # --- Welcome Greeting ---
            faces.play("happy", duration_s=3.0)
            print("Ninja: Hello! I am ready.")
            time.sleep(3.0)
            faces.play("idle", duration_s=float('inf'))
            # ------------------------

            # --- Safety Check Function ---
            last_reaction_time = 0.0
            
            def safety_check() -> bool:
                nonlocal last_reaction_time
                dist = distance_monitor.get_continuous_distance()
                vel = distance_monitor.get_velocity()
                
                # Display distance
                display_dist = dist if dist != -1 else "---"
                print(f"Dist: {display_dist}mm | Vel: {vel:.1f}mm/s   ", end="\r", flush=True)

                # Startle Response Check (Threshold 100mm)
                if distance_monitor.check_emergency_stop(distance_threshold=100):
                    current_time = time.time()
                    if current_time - last_reaction_time > 5.0:
                        last_reaction_time = current_time
                        print()
                        print(f"!!! STARTLE RESPONSE !!! Dist: {dist}mm, Vel: {vel:.2f}mm/s")
                        
                        # Reaction
                        if faces:
                            faces.play("scary", duration_s=2.0)
                        if sound:
                            sound.play("scary") # Blocking in main thread? No, sound.play IS blocking.
                            # We need to run sound in a thread here too or it blocks movement.
                            # But __main__ is sync. We can just let it block for a moment or use threading.
                            # The user said "do not stop servo movements".
                            # If sound.play blocks, servos might stutter if movement is interpolated.
                            # However, MovementController handles interpolation.
                            # But wait, sound.play IS blocking in robot_sound.py?
                            # Let's check robot_sound.py.
                            pass 

                        # We should probably run sound in bg thread if possible, 
                        # but robot_sound.play usually blocks. 
                        # For now, let's just trigger face and return False.
                        # If sound blocks, it stops servos. So we must put sound in thread.
                        threading.Thread(target=sound.play, args=("scary",), daemon=True).start()
                        
                    return False # Do not stop
                return False
            # -----------------------------
            
            while True:
                user_input = input("\nYou: ")
                if user_input.lower() in ["exit", "quit"]:
                    break
                
                print("Ninja is thinking...")
                result = await agent.process_command(user_input)
                
                action_plan = result["action_plan"]
                response_text = result["response"]
                
                # Execute Actions
                # Sound
                if (action_plan.get("sound_chain") or action_plan.get("sound")):
                    chain = action_plan.get("sound_chain", [])
                    if not chain and action_plan.get("sound"):
                        chain = [action_plan.get("sound")]
                    for name in chain:
                        sound.play(name)

                # Face (CLI doesn't run faces in background usually, but here we can)
                # For simplicity in CLI, we might just play the first or iterate blocking?
                # AnimatedFaces.play is non-blocking (starts thread).
                if (action_plan.get("face_chain") or action_plan.get("face")):
                    chain = action_plan.get("face_chain", [])
                    if not chain and action_plan.get("face"):
                        chain = [{"name": action_plan["face"], "duration": 2.0}]
                    
                    for item in chain:
                        name = item.get("name")
                        duration = item.get("duration")
                        faces.play(name)
                        if duration:
                            time.sleep(duration)
                
                if action_plan.get("chain") or action_plan.get("movement"):
                    try:
                        # Chain Logic
                        chain = action_plan.get("chain", [])
                        if not chain and action_plan.get("movement"):
                            chain = [{"name": action_plan["movement"], "repetitions": 1}]

                        for item in chain:
                            move_name = item["name"]
                            reps = item.get("repetitions", 1)
                            for _ in range(reps):
                                if safety_check():
                                     break
                                movement.execute_movement(move_name, abort_check=safety_check)
                    except EmergencyStop:
                        print("!!! OBSTACLE DETECTED - STOPPING !!!")
                        # Reaction: Frightened
                        if faces:
                            faces.play("scary")
                        if sound:
                            sound.play("scary")
                        print("Ninja: Whoa! Too close!")
                
                # Post-Task Reset
                if movement:
                    movement.center_all_servos()
                if faces:
                    faces.play("idle", float('inf'))

                print(f"Ninja: {response_text}")
                
                # --- Idle Status Management ---
                # Return to idle status 3 seconds after completion
                time.sleep(3.0)
                faces.play("idle", duration_s=float('inf'))
                # ------------------------------

        except Exception as e:
            print(f"\nError: {e}")
        finally:
            print("\nShutting down...")
            if faces:
                faces.stop()
            distance_monitor.stop_continuous()
            hal.shutdown()

    asyncio.run(run_chat())


@main.command("server")
@click.option("--autostart", is_flag=True, help="Run in autostart mode (non-interactive).")
def server(autostart):
    """
    Start the NinjaRobot Web Server.
    Provides a web interface for remote control and AI chat.
    """
    from .web_server import run_server
    run_server(autostart=autostart)


if __name__ == "__main__":
    main()

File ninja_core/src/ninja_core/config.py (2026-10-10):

"""
Centralized configuration management for NinjaRobotV4.

This module defines the data structures for the robot's configuration using Pydantic
and provides functions to load, save, and manage the config file.
"""

import json
from pathlib import Path
from typing import Literal, Any, Dict, Optional

from pydantic import ConfigDict, model_validator, BaseModel, Field, field_validator


DEFAULT_BLE_NAME = "NinjaRobot"
MAX_BLE_NAME_BYTES = 29
ROBOT_TYPE_OPTIONS = ("tire", "humanoid", "spider")
ROBOT_TYPE_LABELS = {
    "tire": "Tire",
    "humanoid": "Humanoid",
    "spider": "Spider",
}
DEFAULT_ROBOT_TYPE = "tire"
ROBOT_PROFILE_VERSION = "ninja-robot-profile-v1"
MAX_BCM_GPIO_PIN = 27
DEFAULT_GEMINI_MODEL = "gemini-3-flash-preview"


def normalize_ble_name(name: str) -> str:
    """Normalize and validate the BLE advertising name."""
    normalized = " ".join(name.strip().split())
    if not normalized:
        raise ValueError("Robot name cannot be empty.")

    encoded = normalized.encode("utf-8")
    if len(encoded) > MAX_BLE_NAME_BYTES:
        raise ValueError(
            f"Robot name must fit within {MAX_BLE_NAME_BYTES} UTF-8 bytes for BLE advertising."
        )

    return normalized


def normalize_robot_type(robot_type: str | None) -> str:
    """Normalize and validate the robot type stored in config.json."""
    normalized = (robot_type or DEFAULT_ROBOT_TYPE).strip().lower()
    if normalized == "wheel":
        normalized = "tire"
    if normalized not in ROBOT_TYPE_OPTIONS:
        options = ", ".join(ROBOT_TYPE_OPTIONS)
        raise ValueError(f"Robot type must be one of: {options}.")
    return normalized


def get_robot_type_options() -> tuple[tuple[str, str], ...]:
    """Return supported robot types as (value, label) pairs."""
    return tuple((value, ROBOT_TYPE_LABELS[value]) for value in ROBOT_TYPE_OPTIONS)


def normalize_gemini_model_name(model_name: str) -> str:
    """Normalize a Gemini model identifier for runtime use."""
    normalized = model_name.strip()
    if normalized.startswith("models/"):
        normalized = normalized.removeprefix("models/")
    if not normalized:
        raise ValueError("Gemini model name cannot be empty.")
    return normalized


# --- Data Models for Configuration ---


class ServoCalibration(BaseModel):
    """Stores calibration data for a single servo."""

    min_pulse: int = 500
    center_pulse: int = 1500
    max_pulse: int = 2500
    angle_range: int = 180
    speed: int = 80  # Speed limit percentage (0-100)


class ServosConfig(BaseModel):
    """Configuration for all servos."""

    pins: Dict[str, int] = Field(
        default_factory=dict, description="Mapping of servo names to GPIO pin numbers."
    )
    calibration: Dict[str, ServoCalibration] = Field(
        default_factory=dict,
        description="Calibration data for each servo, keyed by pin number as a string.",
    )


class BuzzerConfig(BaseModel):
    """Configuration for the buzzer."""

    pin: Optional[int] = Field(None, description="The GPIO pin for the buzzer.")


class DisplayConfig(BaseModel):
    """Configuration for the ST7789V display.

    Pin defaults are None to force explicit configuration via
    'ninja_core config import' (reads pi0disp/display.json).
    """

    dc: Optional[int] = Field(None, description="The DC (Data/Command) GPIO pin.")
    rst: Optional[int] = Field(None, description="The RST (Reset) GPIO pin.")
    blk: Optional[int] = Field(None, description="The BLK (Backlight) GPIO pin.")
    rotation: int = Field(
        90, description="Display rotation in degrees (0, 90, 180, 270)."
    )


class SensorConfig(BaseModel):
    """Placeholder for sensor-related settings."""

    # Future settings: I2C address, offsets, etc.
    pass


class BluetoothConfig(BaseModel):
    """Configuration for Bluetooth Low Energy advertising."""

    name: str = Field(
        default=DEFAULT_BLE_NAME,
        description="Bluetooth advertising name shown during robot discovery.",
    )

    @field_validator("name")
    @classmethod
    def validate_name(cls, value: str) -> str:
        return normalize_ble_name(value)


class GeminiConfig(BaseModel):
    """Configuration for the Gemini-powered NinjaRobot agent."""

    model: str = Field(
        default=DEFAULT_GEMINI_MODEL,
        description="Gemini model identifier used for NinjaRobot agent operations.",
    )

    @field_validator("model")
    @classmethod
    def validate_model(cls, value: str) -> str:
        return normalize_gemini_model_name(value)
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

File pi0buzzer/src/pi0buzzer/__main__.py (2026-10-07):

"""
pi0buzzer CLI — Command-line interface for standalone buzzer control.

Provides individual commands for scripting as well as an interactive
``buzzer-tool`` TUI for guided testing and configuration.

Usage::

    uv run pi0buzzer init 17
    uv run pi0buzzer beep 440 0.5
    uv run pi0buzzer play happy
    uv run pi0buzzer info --health-check
    uv run pi0buzzer buzzer-tool
"""

import json
import time

import click

from pi0buzzer.config.config_manager import BuzzerConfigManager
from pi0buzzer.notes import get_emotion_names


# -------------------------------------------------------------------
# Shared helpers
# -------------------------------------------------------------------


def _connect_pigpio():
    """Connect to pigpio daemon.

    Returns:
        pigpio.pi instance.

    Raises:
        click.ClickException: If pigpio is unavailable or daemon not running.
    """
    try:
        import pigpio
    except ImportError:
        raise click.ClickException(
            "pigpio is not installed. Install with:\n"
            "  Standalone: uv sync --extra pi\n"
            "  NinjaRobotV5: uv sync  (pigpio is a main dependency)\n"
            "  Manual: pip install pigpio"
        )

    pi = pigpio.pi()
    if not pi.connected:
        raise click.ClickException(
            "Cannot connect to pigpiod. Start it with: sudo pigpiod"
        )
    return pi


def _create_buzzer(pi, config_path=None):
    """Create and initialize a MusicBuzzer from config.

    Args:
        pi: pigpio.pi instance.
        config_path: Optional path to buzzer.json.

    Returns:
        Initialized MusicBuzzer instance.
    """
    from pi0buzzer.core.music import MusicBuzzer

    cm = BuzzerConfigManager(config_path)
    cm.load()
    pin = cm.get_pin()
    volume = cm.get_volume()

    buzzer = MusicBuzzer(pin=pin, pi=pi, volume=volume)
    buzzer.initialize()
    return buzzer


# -------------------------------------------------------------------
# CLI group
# -------------------------------------------------------------------


@click.group(
    invoke_without_command=True,
    help="pi0buzzer — Passive buzzer driver for Raspberry Pi.",
)
@click.pass_context
@click.option(
    "--config-file", "-C",
    type=str, default=None,
    help="Path to config file (default: buzzer.json).",
)
def cli(ctx, config_file):
    """pi0buzzer CLI tool."""
    ctx.ensure_object(dict)
    ctx.obj["config_file"] = config_file

    if ctx.invoked_subcommand is None:
        click.echo(ctx.get_help())


# -------------------------------------------------------------------
# init command
# -------------------------------------------------------------------


@cli.command()
@click.argument("pin", type=int)
@click.pass_context
def init(ctx, pin):
    """Initialize buzzer config with the given GPIO pin.

    Saves configuration to buzzer.json and plays a test beep.

    Example: uv run pi0buzzer init 17
    """
    cm = BuzzerConfigManager(ctx.obj.get("config_file"))

    try:
        cm.init_config(pin)
        click.echo(f"✓ Buzzer config saved to {cm.path}")
        click.echo(f"  Pin: GPIO {pin}")
    except ValueError as e:
        raise click.ClickException(str(e))

    # Test beep
    try:
        pi = _connect_pigpio()
        from pi0buzzer.core.driver import Buzzer

        buzzer = Buzzer(pin=pin, pi=pi)
        buzzer.initialize()
        click.echo("  Playing test beep...")
        buzzer.play_sound(440, 0.3)
        time.sleep(0.5)
        buzzer.off()
        pi.stop()
        click.echo("✓ Test beep successful!")
    except click.ClickException:
        click.echo("⚠ Could not test beep (pigpiod not running?).")
    except Exception as e:
        click.echo(f"⚠ Test beep failed: {e}")


# -------------------------------------------------------------------
# beep command
# -------------------------------------------------------------------


@cli.command()
@click.argument("frequency", type=int, default=440)
@click.argument("duration", type=float, default=0.5)
@click.pass_context
def beep(ctx, frequency, duration):
    """Play a single tone.

    Example: uv run pi0buzzer beep 440 0.5
    """
    pi = _connect_pigpio()
    try:
        buzzer = _create_buzzer(pi, ctx.obj.get("config_file"))
        click.echo(f"Playing {frequency} Hz for {duration}s...")
        buzzer.play_sound(frequency, duration)
        time.sleep(duration + 0.1)
        buzzer.off()
    finally:
        pi.stop()


# -------------------------------------------------------------------
# play command
# -------------------------------------------------------------------


@cli.command()
@click.argument("emotion", type=str)
@click.pass_context
def play(ctx, emotion):
    """Play a predefined emotion sound.

    Available emotions: happy, sad, exciting, angry, confusing, cry,
    embarrassing, idle, laughing, scary, shy, sleepy, speaking, surprising

    Example: uv run pi0buzzer play happy
    """
    emotions = get_emotion_names()
    if emotion not in emotions:
        raise click.ClickException(
            f"Unknown emotion: '{emotion}'. "
            f"Available: {', '.join(emotions)}"
        )

    pi = _connect_pigpio()
    try:
        buzzer = _create_buzzer(pi, ctx.obj.get("config_file"))
        click.echo(f"Playing emotion: {emotion}")
        buzzer.play_emotion(emotion)
        # Wait for playback to complete
        time.sleep(2.0)
        buzzer.off()
    finally:
        pi.stop()


# -------------------------------------------------------------------
# info command
# -------------------------------------------------------------------


@cli.command()
@click.option(
    "--health-check", is_flag=True,
    help="Verify hardware connectivity.",
)
@click.pass_context
def info(ctx, health_check):
    """Show buzzer configuration and status.

    Example: uv run pi0buzzer info --health-check
    """
    cm = BuzzerConfigManager(ctx.obj.get("config_file"))
    cfg = cm.load()

    click.echo("pi0buzzer Status Report")
    click.echo(f"  Config file: {cm.path}")
    click.echo(f"  Pin:         GPIO {cfg.get('pin', 'N/A')}")
    click.echo(f"  Volume:      {cfg.get('volume', 'N/A')}/255")

    if health_check:
        click.echo("\nHealth Check:")
        try:
            pi = _connect_pigpio()
            click.echo("  ✓ pigpiod connection: OK")

            from pi0buzzer.core.driver import Buzzer

            buzzer = Buzzer(pin=cfg["pin"], pi=pi)
            buzzer.initialize()
            click.echo(f"  ✓ GPIO {cfg['pin']} mode set: OK")

            # Quick beep test
            buzzer.play_sound(440, 0.2)
            time.sleep(0.4)
            buzzer.off()
            click.echo("  ✓ Test beep: OK")

            pi.stop()
            click.echo("\n  Result: All checks passed ✓")
        except click.ClickException as e:
            click.echo(f"  ✗ {e.message}")
        except Exception as e:
            click.echo(f"  ✗ Health check failed: {e}")
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

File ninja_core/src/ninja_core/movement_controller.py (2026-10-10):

import time
import threading
from ninja_core.hal import HardwareAbstractionLayer
from ninja_core.config import NinjaConfig
from ninja_core.builtin_movements import available_movements, validate_movement

from typing import Callable, Optional

class EmergencyStop(Exception):
    """Raised when a movement is aborted due to safety checks."""
    pass


class MovementController:
    """A controller to manage and execute complex, multi-servo movement sequences."""

    def __init__(self, hal: HardwareAbstractionLayer, config: NinjaConfig):
        """
        Initializes the MovementController.

        Args:
            hal: The HardwareAbstractionLayer instance.
            config: The NinjaConfig instance for loading settings.
        """
        self.servos = hal.servos
        self.servo_definitions = config.servos.calibration
        self.movements = config.movements
        self.config = config
        self._motion_lock = threading.RLock()

    def available_movement_names(self) -> list[str]:
        """List only sequences executable on this profile and active channels."""
        pins = self.servos.pins if self.servos else ()
        return available_movements(self.config, pins)

    def validate_movement(self, name: str) -> None:
        pins = self.servos.pins if self.servos else ()
        validate_movement(self.config, name, pins)

    def move_servos(
        self,
        movements: dict[int, float],
        speed: str = "M",
        per_servo_speeds: dict[int, str] | None = None,
        abort_check: Optional[Callable[[], bool]] = None,
        easing: str = "ease_in_out_cubic",
    ):
        """
        Executes a set of servo movements with per-servo velocity control.

        Uses pi0servo's move_all_sync which handles:
        - Per-servo speed limits from calibration
        - Per-servo duration calculation
        - Easing curves for smooth motion

        Args:
            movements: A dictionary of {pin: angle}.
            speed: Global speed mode ('S'low, 'M'edium, 'F'ast).
            per_servo_speeds: Optional {pin: speed} for per-servo override.
            abort_check: Optional function that returns True to abort.
        """
        if not self.servos:
            return

        # Build ordered list of target angles and speed modes
        ordered_pins = self.servos.pins
        target_angles: list[float | None] = []
        speed_modes: list[str] = []

        per_servo_speeds = per_servo_speeds or {}

        for pin in ordered_pins:
            if pin in movements:
                target_angles.append(movements[pin])
                # Use per-servo speed if specified, otherwise global
                servo_speed = per_servo_speeds.get(pin, speed)
                speed_modes.append(servo_speed)
            else:
                # Hold current position (don't move this servo)
                target_angles.append(None)
                speed_modes.append(speed)

        # Use pi0servo's move_all_sync with per-servo speed modes
        # This handles velocity calculation, easing, and abort internally
        with self._motion_lock:
            if abort_check and abort_check():
                raise EmergencyStop("Movement aborted by safety check.")
            completed = self.servos.move_all_sync(
                target_angles,
                speed_mode=speed_modes,
                easing=easing,
                force=True,  # Prevent skipped PWM updates causing limpness
            )
            if not completed or (abort_check and abort_check()):
                # Stop without commanding an unsolicited recovery pose.
                raise EmergencyStop("Movement aborted by driver or safety check.")

    def get_current_angles(self) -> dict[int, float]:
        """
        Returns a dictionary of {pin: current_angle} by mapping the list
        from the driver to its corresponding pins.
        """
        if not self.servos:
            # Return 0 for all known pins if driver is missing
            return {int(pin): 0.0 for pin in self.servo_definitions.keys()}

        angle_list = self.servos.get_all_angles()
        pin_list = self.servos.pins
        return {pin_list[i]: angle_list[i] for i in range(len(pin_list))}

    def center_all_servos(self, abort_check: Optional[Callable[[], bool]] = None):
        """Center servos, optionally guarded by a browser/safety lifecycle."""
        print("Centering all servos...")
        center_angles = {int(pin): 0 for pin in self.servo_definitions.keys()}
        self.move_servos(center_angles, speed="F", abort_check=abort_check)
        time.sleep(0.5)

    def execute_movement(
        self, movement_name: str, abort_check: Optional[Callable[[], bool]] = None
    ):
        """
        Executes a pre-defined movement sequence by name.

        Args:
            movement_name: The name of the movement to execute.
            abort_check: An optional function that returns True if the movement should stop.
        """
        with self._motion_lock:
            self.validate_movement(movement_name)
            self._execute_validated_movement(movement_name, abort_check)

    def _execute_validated_movement(self, movement_name, abort_check):
        print(f"Executing movement: '{movement_name}'...")
        sequence = self.movements[movement_name]
        total_steps = len(sequence)
        
        for i, step in enumerate(sequence):
            # Position-aware easing for smooth transitions
            if total_steps == 1:
                easing = "ease_in_out_cubic"  # Single step: full curve
            elif i == 0:
                easing = "ease_in_cubic"  # First: accelerate only
            elif i == total_steps - 1:
                easing = "ease_out_cubic"  # Last: decelerate to stop
            else:
                easing = "linear"  # Middle: constant velocity
            
            # The keys in 'moves' from JSON will be strings, convert them to int
            moves = {int(k): v for k, v in step["moves"].items()}
            # Extract per-servo speeds if stored (int keys from JSON strings)
            per_servo = None
            if "per_servo_speeds" in step:
                per_servo = {int(k): v for k, v in step["per_servo_speeds"].items()}
            self.move_servos(moves, step["speed"], per_servo, abort_check, easing)
        print(f"Movement '{movement_name}' finished.")

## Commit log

2026-10-07 Initial public NinjaRobotPi0 snapshot
    [NinjaV5_Bottom.stl, NinjaV5_LED.stl, NinjaV5_Middle.stl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]
2026-10-07 Register repository migration evidence in embedded wiki
    [src-20261007-2026-10-07-ninjarobot-pi0-repository-migration.yaml]
2026-10-07 Correct migration documentation and document clean-clone wiki setup
    [src-20261007-2026-10-07-ninjarobot-pi0-migration-audit.yaml, src-20261007-2026-10-07-ninjarobot-pi0-repository-migration.yaml]
2026-10-08 add installer and onboarding tool
    [src-20261007-2026-10-07-ninjarobot-pi0-migration-audit.yaml, src-20261007-2026-10-07-ninjarobot-pi0-repository-migration.yaml]
2026-10-08 fix installer
    [src-20261007-2026-10-07-ninjarobot-pi0-migration-audit.yaml, src-20261007-2026-10-07-ninjarobot-pi0-repository-migration.yaml]
2026-10-08 update installer 02
    [src-20261007-2026-10-07-ninjarobot-pi0-migration-audit.yaml, src-20261007-2026-10-07-ninjarobot-pi0-repository-migration.yaml]
2026-10-08 fix installer 03
    [src-20261007-2026-10-07-ninjarobot-pi0-migration-audit.yaml, src-20261007-2026-10-07-ninjarobot-pi0-repository-migration.yaml]
2026-10-08 refine README.md
    [src-20261007-2026-10-07-ninjarobot-pi0-migration-audit.yaml, src-20261007-2026-10-07-ninjarobot-pi0-repository-migration.yaml]
2026-10-09 create spider build-in movements mapping
    [src-20261007-2026-10-07-ninjarobot-pi0-repository-migration.yaml, src-20261009-2026-10-09-spider-otto.yaml]
2026-10-09 update the wiki
    [src-20261007-2026-10-07-ninjarobot-pi0-migration-audit.yaml, src-20261007-2026-10-07-ninjarobot-pi0-repository-migration.yaml, src-20261009-2026-10-09-spider-o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]
2026-10-10 Model adapter implementation complete
    [src-20261007-2026-10-07-ninjarobot-pi0-migration-audit.yaml, src-20261007-2026-10-07-ninjarobot-pi0-repository-migration.yaml, src-20261009-2026-10-09-spider-o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]
2026-10-11 add servo spider calibration json
2026-10-11 add servo spider calibration json02
2026-10-12 add humanoid servo calibration data
2026-11-12 remove the voice input button on web interface

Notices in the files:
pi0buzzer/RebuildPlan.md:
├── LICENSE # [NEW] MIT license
